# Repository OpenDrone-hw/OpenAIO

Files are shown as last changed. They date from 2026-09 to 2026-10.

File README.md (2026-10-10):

# OpenAIO

An all-in-one for toothpick-class FPV on 2 to 6 cells: flight controller,
4-in-1 ESC and ExpressLRS receiver on 25.5 x 25.5 mm mounting. It merges
three boards OpenDrone already makes: the ESC power stages, power, receiver
and all pads on this board, and the flight controller as the shared
OpenFC-Core module, a 15 x 15 mm LGA reflowed flat onto it, no connector.




The KiCad implementation lives in `hardware/`. Use Git for branch state and
manufacturing or test evidence for maturity claims.

## Why

The three-board stack works and OpenDrone already ships all three parts, but on
a toothpick the stack is most of the weight and all of the height. Merging them
removes two connectors, two sets of mounting hardware and a lot of wiring, and
those connectors are where builds fail.

The parts are proven separately, so this is an integration problem rather than
a research one. The only 6S AIO with onboard serial ELRS on the market is
closed and digital-only; an open one with analog OSD and blackbox has a place,
see the market research linked below.

## Specifications

From the design files. Not manufactured yet.

| | |
|---|---|
| Mounting | 25.5 x 25.5 mm, board 35.4 x 35.4 mm |
| Stack | 6 layers 1.6 mm, 2 oz outer; OpenFC-Core module on top as a 52-pad LGA |
| Input | 2-6S LiPo (6.0-25.2 V) |
| Flight controller | OpenFC-Core module: RP2350-class MCU, IMU, barometer, analog OSD, microSD blackbox; USB-C on this board |
| ESC | 4x AM32, AT32F421 + NSG2065Q per channel like the OpenESC boards |
| Receiver | ExpressLRS 2.4 GHz, ESP32-C3 + SX1281 |
| Assembly | Chosen per release; see production/. LCSC basic parts preferred |

## Constraints

- 25.5 x 25.5 mm mounting, the toothpick standard.
- Runs stock firmware: Betaflight on the FC, AM32 per ESC channel, ExpressLRS
  on the receiver. No forks.
- Reuses the manufactured circuits of OpenFC-Lite-Mini, OpenESC-20x20 and
  OpenRX where they fit; parts come from the shared library first.
- Assembly from LCSC parts, extended parts kept to a minimum; assembly house
  chosen per release, see production/.
- Do not start from the three schematics stitched together. That was tried,
  and it produced a board that looked finished and was not (recoverable at the
  `pre-reset-2026-08-13` tag). Start from the requirements.

## Prior art

The three designs this merges, all manufactured and flying:

- [OpenFC-Lite-Mini](https://github.com/OpenDrone-hw/OpenFC-Lite-Mini): the RP2354A flight controller
- [OpenESC-20x20](https://github.com/OpenDrone-hw/OpenESC-20x20): the AM32 4-in-1 power stage
- [OpenRX Lite](https://github.com/OpenDrone-hw/OpenRX-Lite): the ELRS receiver

Research so far, reference rather than decisions:

- [Market research](https://app.notion.com/p/3f5fe06764e1818e9158c512edd58138): competing toothpick and whoop AIOs, June 2026
- [Part alternatives](https://app.notion.com/p/3f5fe06764e1819eade0dc5bfbfdff7c): ESC-stage part alternatives, gate driver and FET options, March 2026
- The stitched design reset in August 2026 is in the git history before #9; reference for the thinking, not a design to continue from.

## Design questions

Resolve these only as part of user-requested design work:

- **Thermal.** Four power stages next to an MCU and a radio on 25.5 mm square,
  with no airflow guarantee. What is the continuous current budget on 2 oz
  outer copper?
- **RF isolation.** A 2.4 GHz receiver next to four switching power stages.
  Antenna placement, ground plane, shield can or not.

## In the line

What pairs with what, and what is available:
[opendrone.be](https://opendrone.be).

## Contributing

KiCad files cannot be merged, so say what you intend to change before you do,
on [Discord](https://discord.gg/v3sWmTcx3R). How everything works:
[CONTRIBUTING.md](CONTRIBUTING.md).

## License

Hardware licensed under [CERN-OHL-S-2.0](https://ohwr.org/cern_ohl_s_v2.txt),
see [LICENSE](LICENSE).

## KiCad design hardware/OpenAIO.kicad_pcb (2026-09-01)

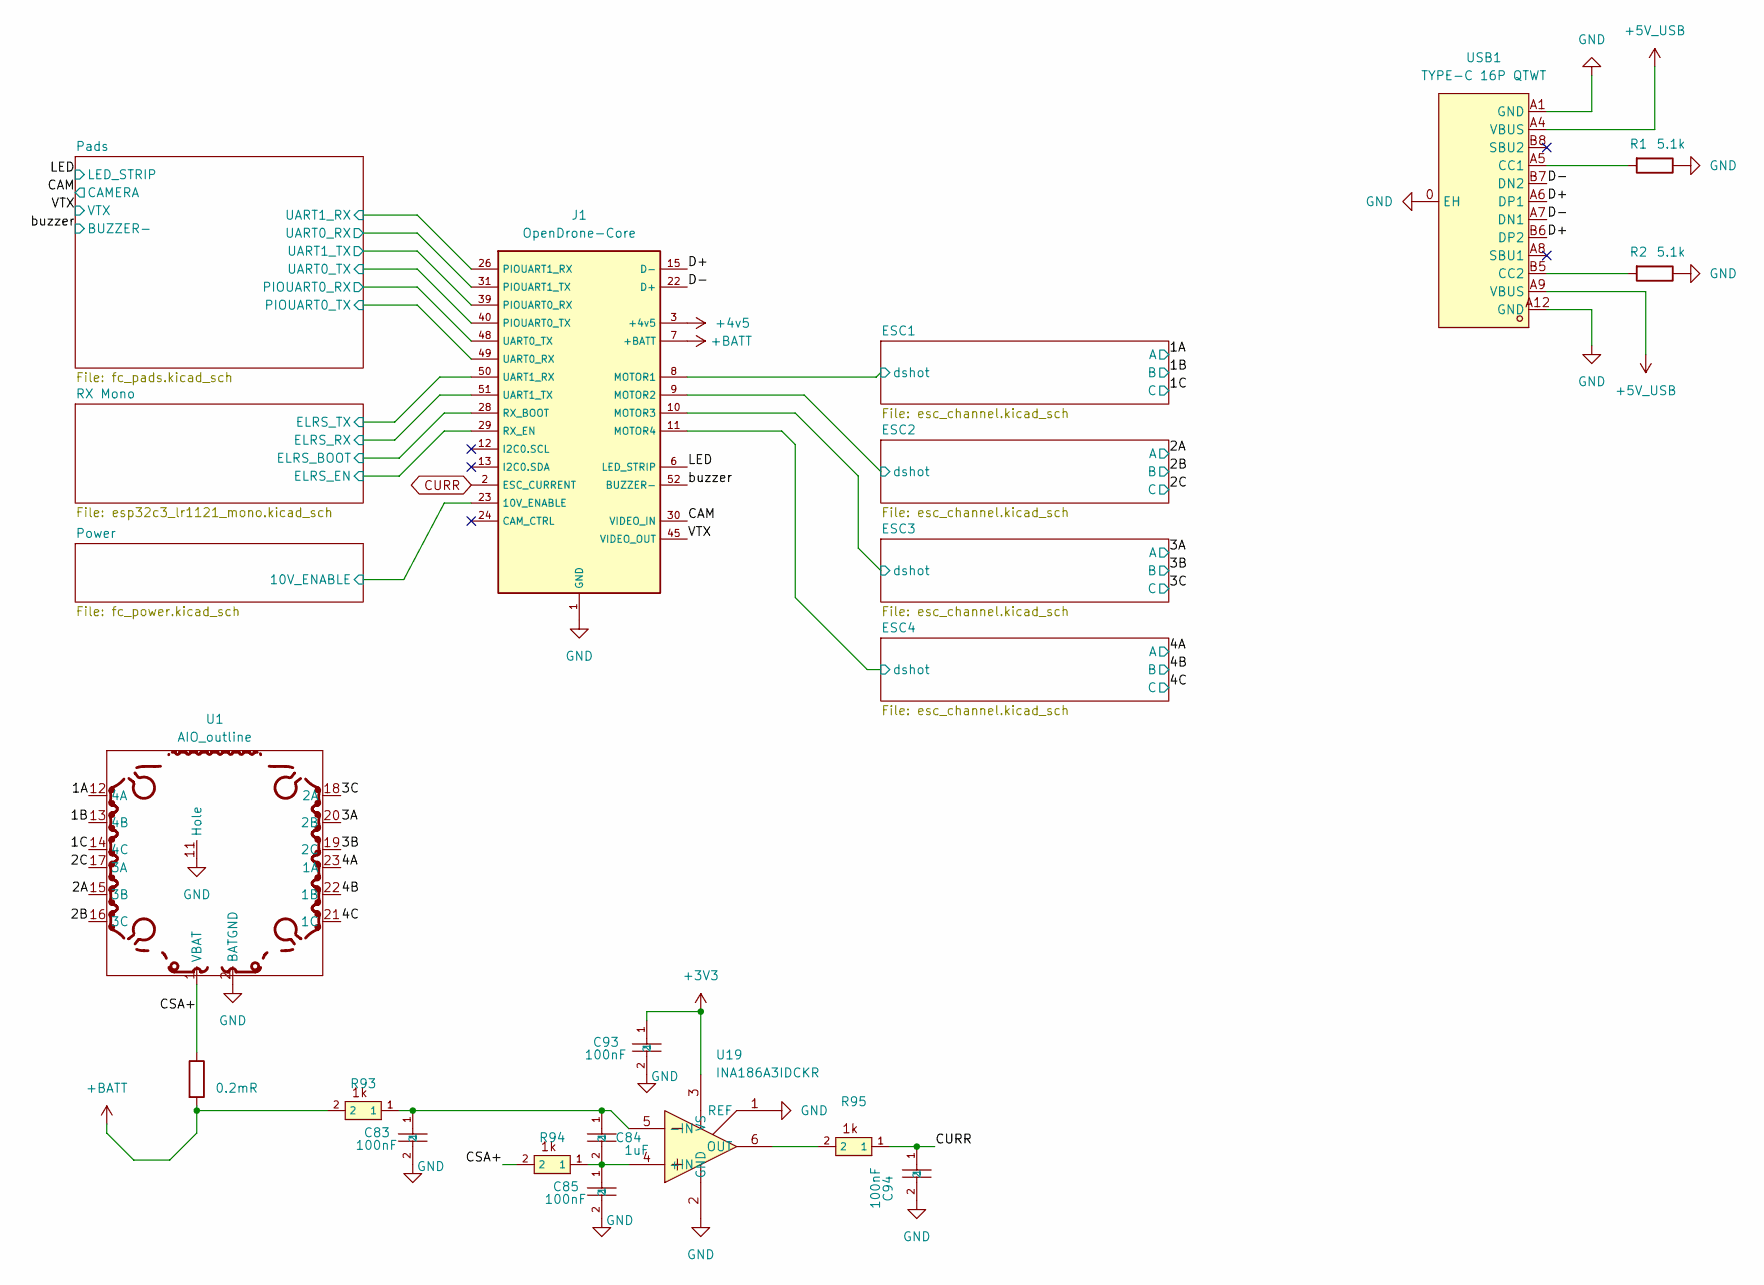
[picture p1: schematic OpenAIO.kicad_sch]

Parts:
C83, C85: 100nF; C_0402_WIDE; MPN CL05B104KB54PNC; LCSC C307331
C84: 1uF; C_0402_1005Metric; MPN CC0402KRX7R6BB105; LCSC C7500381
C93, C94: 100nF; C_0201_0603Metric; MPN GRM033R6YA104KE14D; LCSC C181043
J1: OpenDrone-Core; OpenDrone-Core_LGA_land
R1, R2: 5.1k; R_0201_0603Metric; MPN 0201WMF5101TEE; LCSC C270344
R93, R94: 1k; C_0201_0603Metric; MPN 0201WMF1001TEE; LCSC C270365
R95: 1k; R_0201_0603Metric; MPN 0201WMF1001TEE; LCSC C270365
Rsense2: 0.2mR; R_2512_6332Metric; MPN ASR-S-3-0.2F; LCSC C695806
U1: AIO_outline
U19: INA186A3IDCKR; SOT-363_SC-70-6; MPN INA186A3IDCKR; LCSC C2058245
USB1: TYPE-C 16P QTWT; USB-TYPE-C-SMD_TYPE-C-16P-QTWT; MPN TYPE-C 16P QTWT; LCSC C5187472

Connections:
+3V3: C93.1, U19.3 (VS); also elsewhere on the board
+4v5: J1.3 (+4v5); also elsewhere on the board
+5V_USB: USB1.A4 (VBUS), USB1.A9 (VBUS); also elsewhere on the board
+BATT: J1.7 (+BATT), R93.2, Rsense2.2; also elsewhere on the board
/1A: U1.12 (4A); also elsewhere on the board
/1B: U1.13 (4B); also elsewhere on the board
/1C: U1.14 (4C); also elsewhere on the board
/2A: U1.15 (3B); also elsewhere on the board
/2B: U1.16 (3C); also elsewhere on the board
/2C: U1.17 (3A); also elsewhere on the board
/3A: U1.20 (2B); also elsewhere on the board
/3B: U1.19 (2C); also elsewhere on the board
/3C: U1.18 (2A); also elsewhere on the board
/4A: U1.23 (1A); also elsewhere on the board
/4B: U1.22 (1B); also elsewhere on the board
/4C: U1.21 (1C); also elsewhere on the board
/CAM: J1.30 (VIDEO_IN); also elsewhere on the board
/CSA+: R94.2, Rsense2.1, U1.1 (VBAT)
/D+: J1.15 (D-), USB1.A6 (DP1), USB1.B6 (DP2)
/D-: J1.22 (D+), USB1.A7 (DN1), USB1.B7 (DN2)
/ESC1/dshot: J1.8 (MOTOR1); also elsewhere on the board
/ESC2/dshot: J1.9 (MOTOR2); also elsewhere on the board
/ESC3/dshot: J1.10 (MOTOR3); also elsewhere on the board
/ESC4/dshot: J1.11 (MOTOR4); also elsewhere on the board
/LED: J1.6 (LED_STRIP); also elsewhere on the board
/Pads/PIOUART0_TX: J1.49 (UART0_RX); also elsewhere on the board
/Pads/PU0RX: J1.48 (UART0_TX); also elsewhere on the board
/Pads/U1RX: J1.26 (PIOUART1_RX); also elsewhere on the board
/Pads/UART0_RX: J1.31 (PIOUART1_TX); also elsewhere on the board
/Pads/UART0_TX: J1.40 (PIOUART0_TX); also elsewhere on the board
/Pads/UART1_TX: J1.39 (PIOUART0_RX); also elsewhere on the board
/Power/10V_ENABLE: J1.23 (10V_ENABLE); also elsewhere on the board
/RX Mono/CHIP_EN: J1.29 (RX_EN); also elsewhere on the board
/RX Mono/ELRS_RX: J1.51 (UART1_TX); also elsewhere on the board
/RX Mono/ELRS_TX: J1.50 (UART1_RX); also elsewhere on the board
/VTX: J1.45 (VIDEO_OUT); also elsewhere on the board
/buzzer: J1.52 (BUZZER-); also elsewhere on the board
CURR: C94.1, R95.1
GND: C83.2, C85.2, C93.2, C94.2, J1.1 (GND), J1.4 (GND), J1.5 (GND), J1.14 (GND), J1.16 (GND), J1.17 (GND), J1.18 (GND), J1.19 (GND), J1.20 (GND), J1.21 (GND), J1.25 (GND), J1.27 (GND), J1.32 (GND), J1.33 (GND), J1.34 (GND), J1.35 (GND), J1.36 (GND), J1.37 (GND), J1.38 (GND), J1.41 (GND), J1.42 (GND), J1.43 (GND), J1.44 (GND), J1.46 (GND), J1.47 (GND), R1.1, R2.1, U1.2 (BATGND), U1.11 (Hole), U19.1 (REF), U19.2 (GND), USB1.0 (EH), USB1.A1 (GND), USB1.A12 (GND); also elsewhere on the board
unnamed: C84.2, C85.1, R94.1, U19.4 (+IN)
unnamed: C83.1, C84.1, R93.1, U19.5 (-IN)
unnamed: R95.2, U19.6 (OUT)
unnamed: R1.2, USB1.A5 (CC1)
unnamed: R2.2, USB1.B5 (CC2)

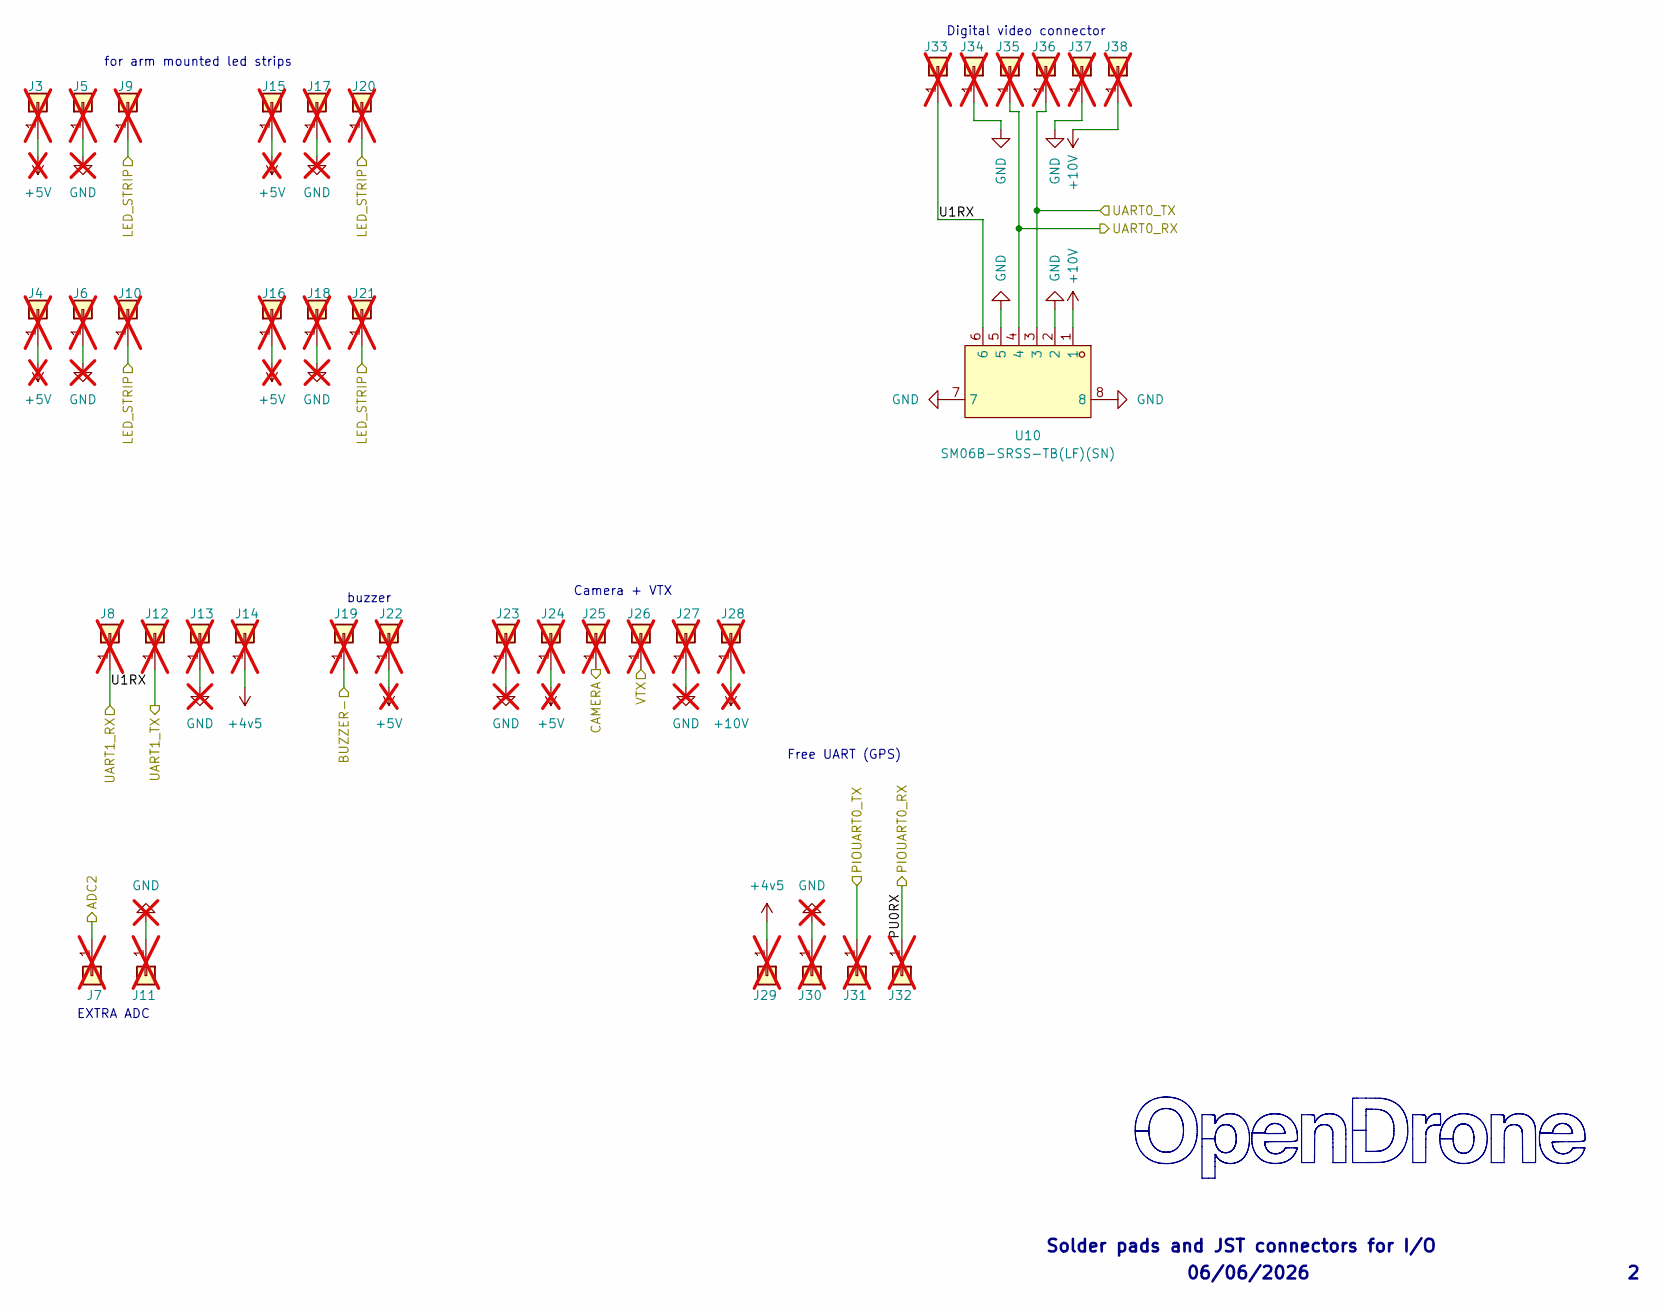
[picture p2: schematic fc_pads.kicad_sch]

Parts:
J3, J4, J5, J6, J7, J8, J9, J10, J11, J12, J13, J14, J15, J16, J17, J18, J19, J20, J21, J22, J23, J24, J25, J26, J27, J28, J29, J30, J31, J32, J33, J34, J35, J36, J37, J38: 5V; small_pad; not fitted
U10: SM06B-SRSS-TB(LF)(SN); CONN-SMD_SM06B-SRSS-TB-LF-SN; MPN SM06B-SRSS-TB(LF)(SN); LCSC C160405

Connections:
+4v5: J14.1 (Pin_1_1), J29.1 (Pin_1_1); also elsewhere on the board
+5V: J3.1 (Pin_1_1), J4.1 (Pin_1_1), J15.1 (Pin_1_1), J16.1 (Pin_1_1), J22.1 (Pin_1_1), J24.1 (Pin_1_1); also elsewhere on the board
+10V: J28.1 (Pin_1_1), J38.1 (Pin_1_1), U10.1; also elsewhere on the board
/CAM: J25.1 (Pin_1_1); also elsewhere on the board
/LED: J9.1 (Pin_1_1), J10.1 (Pin_1_1), J20.1 (Pin_1_1), J21.1 (Pin_1_1); also elsewhere on the board
/Pads/PIOUART0_TX: J31.1 (Pin_1_1); also elsewhere on the board
/Pads/PU0RX: J32.1 (Pin_1_1); also elsewhere on the board
/Pads/U1RX: J8.1 (Pin_1_1), J33.1, U10.6; also elsewhere on the board
/Pads/UART0_RX: J35.1 (Pin_1_1), U10.4; also elsewhere on the board
/Pads/UART0_TX: J36.1 (Pin_1_1), U10.3; also elsewhere on the board
/Pads/UART1_TX: J12.1 (Pin_1_1); also elsewhere on the board
/VTX: J26.1 (Pin_1_1); also elsewhere on the board
/buzzer: J19.1 (Pin_1_1); also elsewhere on the board
GND: J5.1 (Pin_1_1), J6.1 (Pin_1_1), J11.1, J13.1 (Pin_1_1), J17.1 (Pin_1_1), J18.1 (Pin_1_1), J23.1 (Pin_1_1), J27.1 (Pin_1_1), J30.1 (Pin_1_1), J34.1, J37.1 (Pin_1_1), U10.2, U10.5, U10.7, U10.8; also elsewhere on the board

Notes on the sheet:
Free UART (GPS)
Solder pads and JST connectors for I/O
06/06/2026
buzzer
Camera + VTX
Digital video connector
EXTRA ADC
for arm mounted led strips

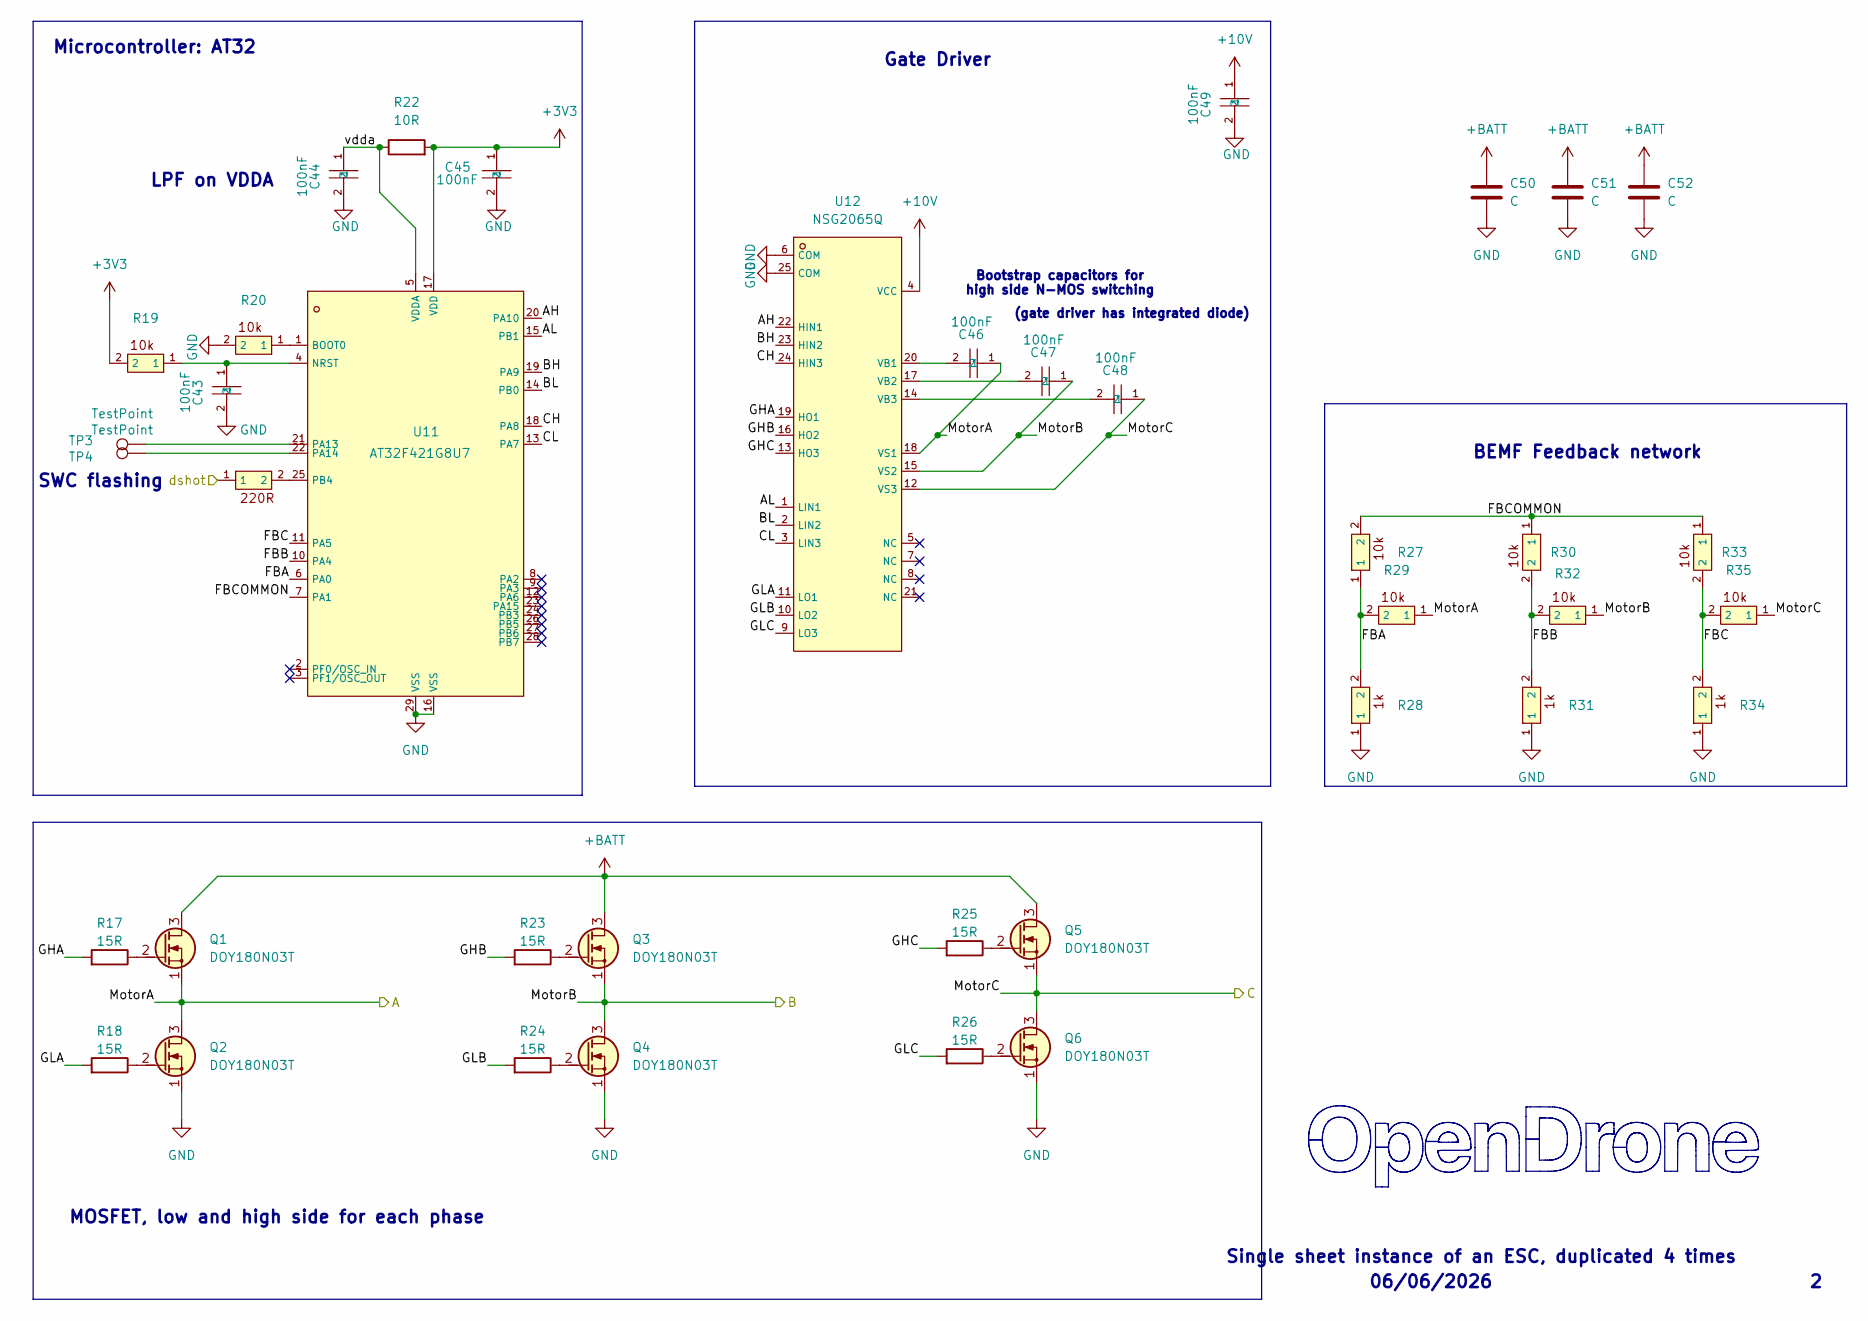
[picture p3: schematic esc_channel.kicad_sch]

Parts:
C43, C44, C45, C49: 100nF; C_0201_0603Metric; MPN GRM033R6YA104KE14D; LCSC C181043
C46, C47, C48: 100nF; C_0402_WIDE; MPN CL05B104KB54PNC; LCSC C307331
C50, C51, C52: C; C_0805_2012Metric
Q1, Q2, Q3, Q4, Q5, Q6: DOY180N03T; Diodes_PowerDI3333-8; MPN DOY180N03T; LCSC C49441966
R17, R18, R23, R24, R25, R26: 15R; R_0201_0603Metric; MPN 0201WMF150JTEE; LCSC C473542
R19, R20, R27, R29, R30, R32, R33, R35: 10k; R_0201_0603Metric; MPN RC0201FR-0710KL; LCSC C106225
R21: 220R; R_0201_0603Metric; MPN AC0201FR-07220RL; LCSC C226468
R22: 10R; R_0201_0603Metric; MPN RC0201FR-0710RL; LCSC C106226
R28, R31, R34: 1k; R_0201_0603Metric; MPN 0201WMF1001TEE; LCSC C270365
TP3, TP4: TestPoint; TestPoint_Pad_D1.0mm
U11: AT32F421G8U7; QFN-28_L4.0-W4.0-P0.40-TL-EP2.4; MPN AT32F421G8U7; LCSC C2765098
U12: NSG2065Q; QFN-24_L4.0-W4.0-P0.50-TL-EP2.8; MPN NSG2065Q; LCSC C41414478

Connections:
+3V3: C45.1, R19.2, R22.2, U11.17 (VDD); also elsewhere on the board
+10V: C49.1, U12.4 (VCC); also elsewhere on the board
+BATT: C50.1, C51.1, C52.1, Q1.3 (D), Q3.3 (D), Q5.3 (D); also elsewhere on the board
/1A: C46.1, Q1.1 (S), Q2.3 (D), R29.1, U12.18 (VS1); also elsewhere on the board
/1B: C47.1, Q3.1 (S), Q4.3 (D), R32.1, U12.15 (VS2); also elsewhere on the board
/1C: C48.1, Q5.1 (S), Q6.3 (D), R35.1, U12.12 (VS3); also elsewhere on the board
/ESC1/AH: U11.20 (PA10), U12.22 (HIN1)
/ESC1/AL: U11.15 (PB1), U12.1 (LIN1)
/ESC1/BH: U11.19 (PA9), U12.23 (HIN2)
/ESC1/BL: U11.14 (PB0), U12.2 (LIN2)
/ESC1/CH: U11.18 (PA8), U12.24 (HIN3)
/ESC1/CL: U11.13 (PA7), U12.3 (LIN3)
/ESC1/FBA: R27.1, R28.2, R29.2, U11.6 (PA0)
/ESC1/FBB: R30.2, R31.2, R32.2, U11.10 (PA4)
/ESC1/FBC: R33.2, R34.2, R35.2, U11.11 (PA5)
/ESC1/FBCOMMON: R27.2, R30.1, R33.1, U11.7 (PA1)
/ESC1/GHA: R17.1, U12.19 (HO1)
/ESC1/GHB: R23.1, U12.16 (HO2)
/ESC1/GHC: R25.1, U12.13 (HO3)
/ESC1/GLA: R18.1, U12.11 (LO1)
/ESC1/GLB: R24.1, U12.10 (LO2)
/ESC1/GLC: R26.1, U12.9 (LO3)
/ESC1/dshot: R21.1; also elsewhere on the board
/ESC1/vdda: C44.1, R22.1, U11.5 (VDDA)
GND: C43.2, C44.2, C45.2, C49.2, C50.2, C51.2, C52.2, Q2.1 (S), Q4.1 (S), Q6.1 (S), R20.2, R28.1, R31.1, R34.1, U11.16 (VSS), U11.29 (VSS), U12.6 (COM), U12.25 (COM); also elsewhere on the board
unnamed: Q1.2 (G), R17.2
unnamed: Q2.2 (G), R18.2
unnamed: Q3.2 (G), R23.2
unnamed: Q4.2 (G), R24.2
unnamed: Q5.2 (G), R25.2
unnamed: Q6.2 (G), R26.2
unnamed: R20.1, U11.1 (BOOT0)
unnamed: C43.1, R19.1, U11.4 (NRST)
unnamed: TP3.1 (1_1), U11.21 (PA13)
unnamed: TP4.1 (1_1), U11.22 (PA14)
unnamed: R21.2, U11.25 (PB4)
unnamed: C46.2, U12.20 (VB1)
unnamed: C47.2, U12.17 (VB2)
unnamed: C48.2, U12.14 (VB3)

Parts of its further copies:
C53, C56, C58, C66, C67, C68, C73, C76, C78: 100nF; C_0402_WIDE; MPN CL05B104KB54PNC; LCSC C307331
C54, C55, C57, C59, C63, C64, C65, C69, C74, C75, C77, C79: 100nF; C_0201_0603Metric; MPN GRM033R6YA104KE14D; LCSC C181043
C60, C61, C62, C70, C71, C72, C80, C81, C82: C; C_0805_2012Metric
Q7, Q8, Q9, Q10, Q11, Q12, Q13, Q14, Q15, Q16, Q17, Q18, Q19, Q20, Q21, Q22, Q23, Q24: DOY180N03T; Diodes_PowerDI3333-8; MPN DOY180N03T; LCSC C49441966
R37, R42, R43, R44, R45, R55, R56, R61, R62, R63, R64, R80, R81, R82, R83: 15R; R_0201_0603Metric; MPN 0201WMF150JTEE; LCSC C473542
R38, R39, R46, R48, R49, R51, R52, R54, R57, R58, R67, R68, R70, R73, R76, R84, R86, R87, R89, R90, R92: 10k; R_0201_0603Metric; MPN RC0201FR-0710KL; LCSC C106225
R40, R59, R78: 220R; R_0201_0603Metric; MPN AC0201FR-07220RL; LCSC C226468
R47, R50, R53, R66, R69, R72, R85, R88, R91: 1k; R_0201_0603Metric; MPN 0201WMF1001TEE; LCSC C270365
R60, R79: 10R; R_0201_0603Metric; MPN RC0201FR-0710RL; LCSC C106226
TP5, TP6, TP7, TP8, TP9, TP10: TestPoint; TestPoint_Pad_D1.0mm
U13, U15, U17: AT32F421G8U7; QFN-28_L4.0-W4.0-P0.40-TL-EP2.4; MPN AT32F421G8U7; LCSC C2765098
U14, U16, U18: NSG2065Q; QFN-24_L4.0-W4.0-P0.50-TL-EP2.8; MPN NSG2065Q; LCSC C41414478

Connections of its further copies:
+3V3: C55.1, C65.1, C75.1, R38.2, R57.2, R60.2, R76.2, R79.2, U13.17 (VDD), U15.17 (VDD), U17.17 (VDD); also elsewhere on the board
+10V: C59.1, C69.1, C79.1, U14.4 (VCC), U16.4 (VCC), U18.4 (VCC); also elsewhere on the board
+BATT: C60.1, C61.1, C62.1, C70.1, C71.1, C72.1, C80.1, C81.1, C82.1, Q7.3 (D), Q9.3 (D), Q11.3 (D), Q13.3 (D), Q15.3 (D), Q17.3 (D), Q19.3 (D), Q21.3 (D), Q23.3 (D); also elsewhere on the board
/2A: C56.1, Q7.1 (S), Q8.3 (D), R48.1, U14.18 (VS1); also elsewhere on the board
/2B: C57.1, Q9.1 (S), Q10.3 (D), R51.1, U14.15 (VS2); also elsewhere on the board
/2C: C58.1, Q11.1 (S), Q12.3 (D), R54.1, U14.12 (VS3); also elsewhere on the board
/3A: C66.1, Q13.1 (S), Q14.3 (D), R67.1, U16.18 (VS1); also elsewhere on the board
/3B: C67.1, Q15.1 (S), Q16.3 (D), R70.1, U16.15 (VS2); also elsewhere on the board
/3C: C68.1, Q17.1 (S), Q18.3 (D), R73.1, U16.12 (VS3); also elsewhere on the board
/4A: C76.1, Q19.1 (S), Q20.3 (D), R86.1, U18.18 (VS1); also elsewhere on the board
/4B: C77.1, Q21.1 (S), Q22.3 (D), R89.1, U18.15 (VS2); also elsewhere on the board
/4C: C78.1, Q23.1 (S), Q24.3 (D), R92.1, U18.12 (VS3); also elsewhere on the board
/ESC2/AH: U13.20 (PA10), U14.22 (HIN1)
/ESC2/AL: U13.15 (PB1), U14.1 (LIN1)
/ESC2/BH: U13.19 (PA9), U14.23 (HIN2)
/ESC2/BL: U13.14 (PB0), U14.2 (LIN2)
/ESC2/CH: U13.18 (PA8), U14.24 (HIN3)
/ESC2/CL: U13.13 (PA7), U14.3 (LIN3)
/ESC2/FBA: R46.1, R47.2, R48.2, U13.6 (PA0)
/ESC2/FBB: R49.2, R50.2, R51.2, U13.10 (PA4)
/ESC2/FBC: R52.2, R53.2, R54.2, U13.11 (PA5)
/ESC2/FBCOMMON: R46.2, R49.1, R52.1, U13.7 (PA1)
/ESC2/GHA: U14.19 (HO1); also elsewhere on the board
/ESC2/GHB: R42.1, U14.16 (HO2)
/ESC2/GHC: R44.1, U14.13 (HO3)
/ESC2/GLA: R37.1, U14.11 (LO1)
/ESC2/GLB: R43.1, U14.10 (LO2)
/ESC2/GLC: R45.1, U14.9 (LO3)
/ESC2/dshot: R40.1; also elsewhere on the board
/ESC2/vdda: C54.1, U13.5 (VDDA); also elsewhere on the board
/ESC3/AH: U15.20 (PA10), U16.22 (HIN1)
/ESC3/AL: U15.15 (PB1), U16.1 (LIN1)
/ESC3/BH: U15.19 (PA9), U16.23 (HIN2)
/ESC3/BL: U15.14 (PB0), U16.2 (LIN2)
/ESC3/CH: U15.18 (PA8), U16.24 (HIN3)
/ESC3/CL: U15.13 (PA7), U16.3 (LIN3)
/ESC3/FBA: R66.2, R67.2, U15.6 (PA0); also elsewhere on the board
/ESC3/FBB: R68.2, R69.2, R70.2, U15.10 (PA4)
/ESC3/FBC: R72.2, R73.2, U15.11 (PA5); also elsewhere on the board
/ESC3/FBCOMMON: R68.1, U15.7 (PA1); also elsewhere on the board
/ESC3/GHA: R55.1, U16.19 (HO1)
/ESC3/GHB: R61.1, U16.16 (HO2)
/ESC3/GHC: R63.1, U16.13 (HO3)
/ESC3/GLA: R56.1, U16.11 (LO1)
/ESC3/GLB: R62.1, U16.10 (LO2)
/ESC3/GLC: R64.1, U16.9 (LO3)
/ESC3/dshot: R59.1; also elsewhere on the board
/ESC3/vdda: C64.1, R60.1, U15.5 (VDDA)
/ESC4/AH: U17.20 (PA10), U18.22 (HIN1)
/ESC4/AL: U17.15 (PB1), U18.1 (LIN1)
/ESC4/BH: U17.19 (PA9), U18.23 (HIN2)
/ESC4/BL: U17.14 (PB0), U18.2 (LIN2)
/ESC4/CH: U17.18 (PA8), U18.24 (HIN3)
/ESC4/CL: U17.13 (PA7), U18.3 (LIN3)
/ESC4/FBA: R84.1, R85.2, R86.2, U17.6 (PA0)
/ESC4/FBB: R87.2, R88.2, R89.2, U17.10 (PA4)
/ESC4/FBC: R90.2, R91.2, R92.2, U17.11 (PA5)
/ESC4/FBCOMMON: R84.2, R87.1, R90.1, U17.7 (PA1)
/ESC4/GHA: U18.19 (HO1); also elsewhere on the board
/ESC4/GHB: R80.1, U18.16 (HO2)
/ESC4/GHC: R82.1, U18.13 (HO3)
/ESC4/GLA: U18.11 (LO1); also elsewhere on the board
/ESC4/GLB: R81.1, U18.10 (LO2)
/ESC4/GLC: R83.1, U18.9 (LO3)
/ESC4/dshot: R78.1; also elsewhere on the board
/ESC4/vdda: C74.1, R79.1, U17.5 (VDDA)
GND: C53.2, C54.2, C55.2, C59.2, C60.2, C61.2, C62.2, C63.2, C64.2, C65.2, C69.2, C70.2, C71.2, C72.2, C73.2, C74.2, C75.2, C79.2, C80.2, C81.2, C82.2, Q8.1 (S), Q10.1 (S), Q12.1 (S), Q14.1 (S), Q16.1 (S), Q18.1 (S), Q20.1 (S), Q22.1 (S), Q24.1 (S), R39.2, R47.1, R50.1, R53.1, R58.2, R66.1, R69.1, R72.1, R85.1, R88.1, R91.1, U13.16 (VSS), U13.29 (VSS), U14.6 (COM), U14.25 (COM), U15.16 (VSS), U15.29 (VSS), U16.6 (COM), U16.25 (COM), U17.16 (VSS), U17.29 (VSS), U18.6 (COM), U18.25 (COM); also elsewhere on the board
unnamed 141: Q7.2 (G); also elsewhere on the board
unnamed: Q8.2 (G), R37.2
unnamed: Q9.2 (G), R42.2
unnamed: Q10.2 (G), R43.2
unnamed: Q11.2 (G), R44.2
unnamed: Q12.2 (G), R45.2
unnamed: Q13.2 (G), R55.2
unnamed: Q14.2 (G), R56.2
unnamed: Q15.2 (G), R61.2
unnamed: Q16.2 (G), R62.2
unnamed: Q17.2 (G), R63.2
unnamed: Q18.2 (G), R64.2
unnamed 153: Q19.2 (G); also elsewhere on the board
unnamed 154: Q20.2 (G); also elsewhere on the board
unnamed: Q21.2 (G), R80.2
unnamed: Q22.2 (G), R81.2
unnamed: Q23.2 (G), R82.2
unnamed: Q24.2 (G), R83.2
unnamed: R39.1, U13.1 (BOOT0)
unnamed: C53.1, R38.1, U13.4 (NRST)
unnamed: TP5.1 (1_1), U13.21 (PA13)
unnamed: TP6.1 (1_1), U13.22 (PA14)
unnamed: R40.2, U13.25 (PB4)
unnamed: C56.2, U14.20 (VB1)
unnamed: C57.2, U14.17 (VB2)
unnamed: C58.2, U14.14 (VB3)
unnamed: R58.1, U15.1 (BOOT0)
unnamed: C63.1, R57.1, U15.4 (NRST)
unnamed: TP7.1 (1_1), U15.21 (PA13)
unnamed: TP8.1 (1_1), U15.22 (PA14)
unnamed: R59.2, U15.25 (PB4)
unnamed: C66.2, U16.20 (VB1)
unnamed: C67.2, U16.17 (VB2)
unnamed: C68.2, U16.14 (VB3)
unnamed 202: U17.1 (BOOT0); also elsewhere on the board
unnamed: C73.1, R76.1, U17.4 (NRST)
unnamed: TP9.1 (1_1), U17.21 (PA13)
unnamed: TP10.1 (1_1), U17.22 (PA14)
unnamed: R78.2, U17.25 (PB4)
unnamed: C76.2, U18.20 (VB1)
unnamed: C77.2, U18.17 (VB2)
unnamed: C78.2, U18.14 (VB3)

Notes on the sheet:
Bootstrap capacitors for high side N-MOS switching
Gate Driver
MOSFET, low and high side for each phase
Single sheet instance of an ESC, duplicated 4 times
Microcontroller: AT32
SWC flashing
(gate driver has integrated diode)
06/06/2026
BEMF Feedback network
LPF on VDDA

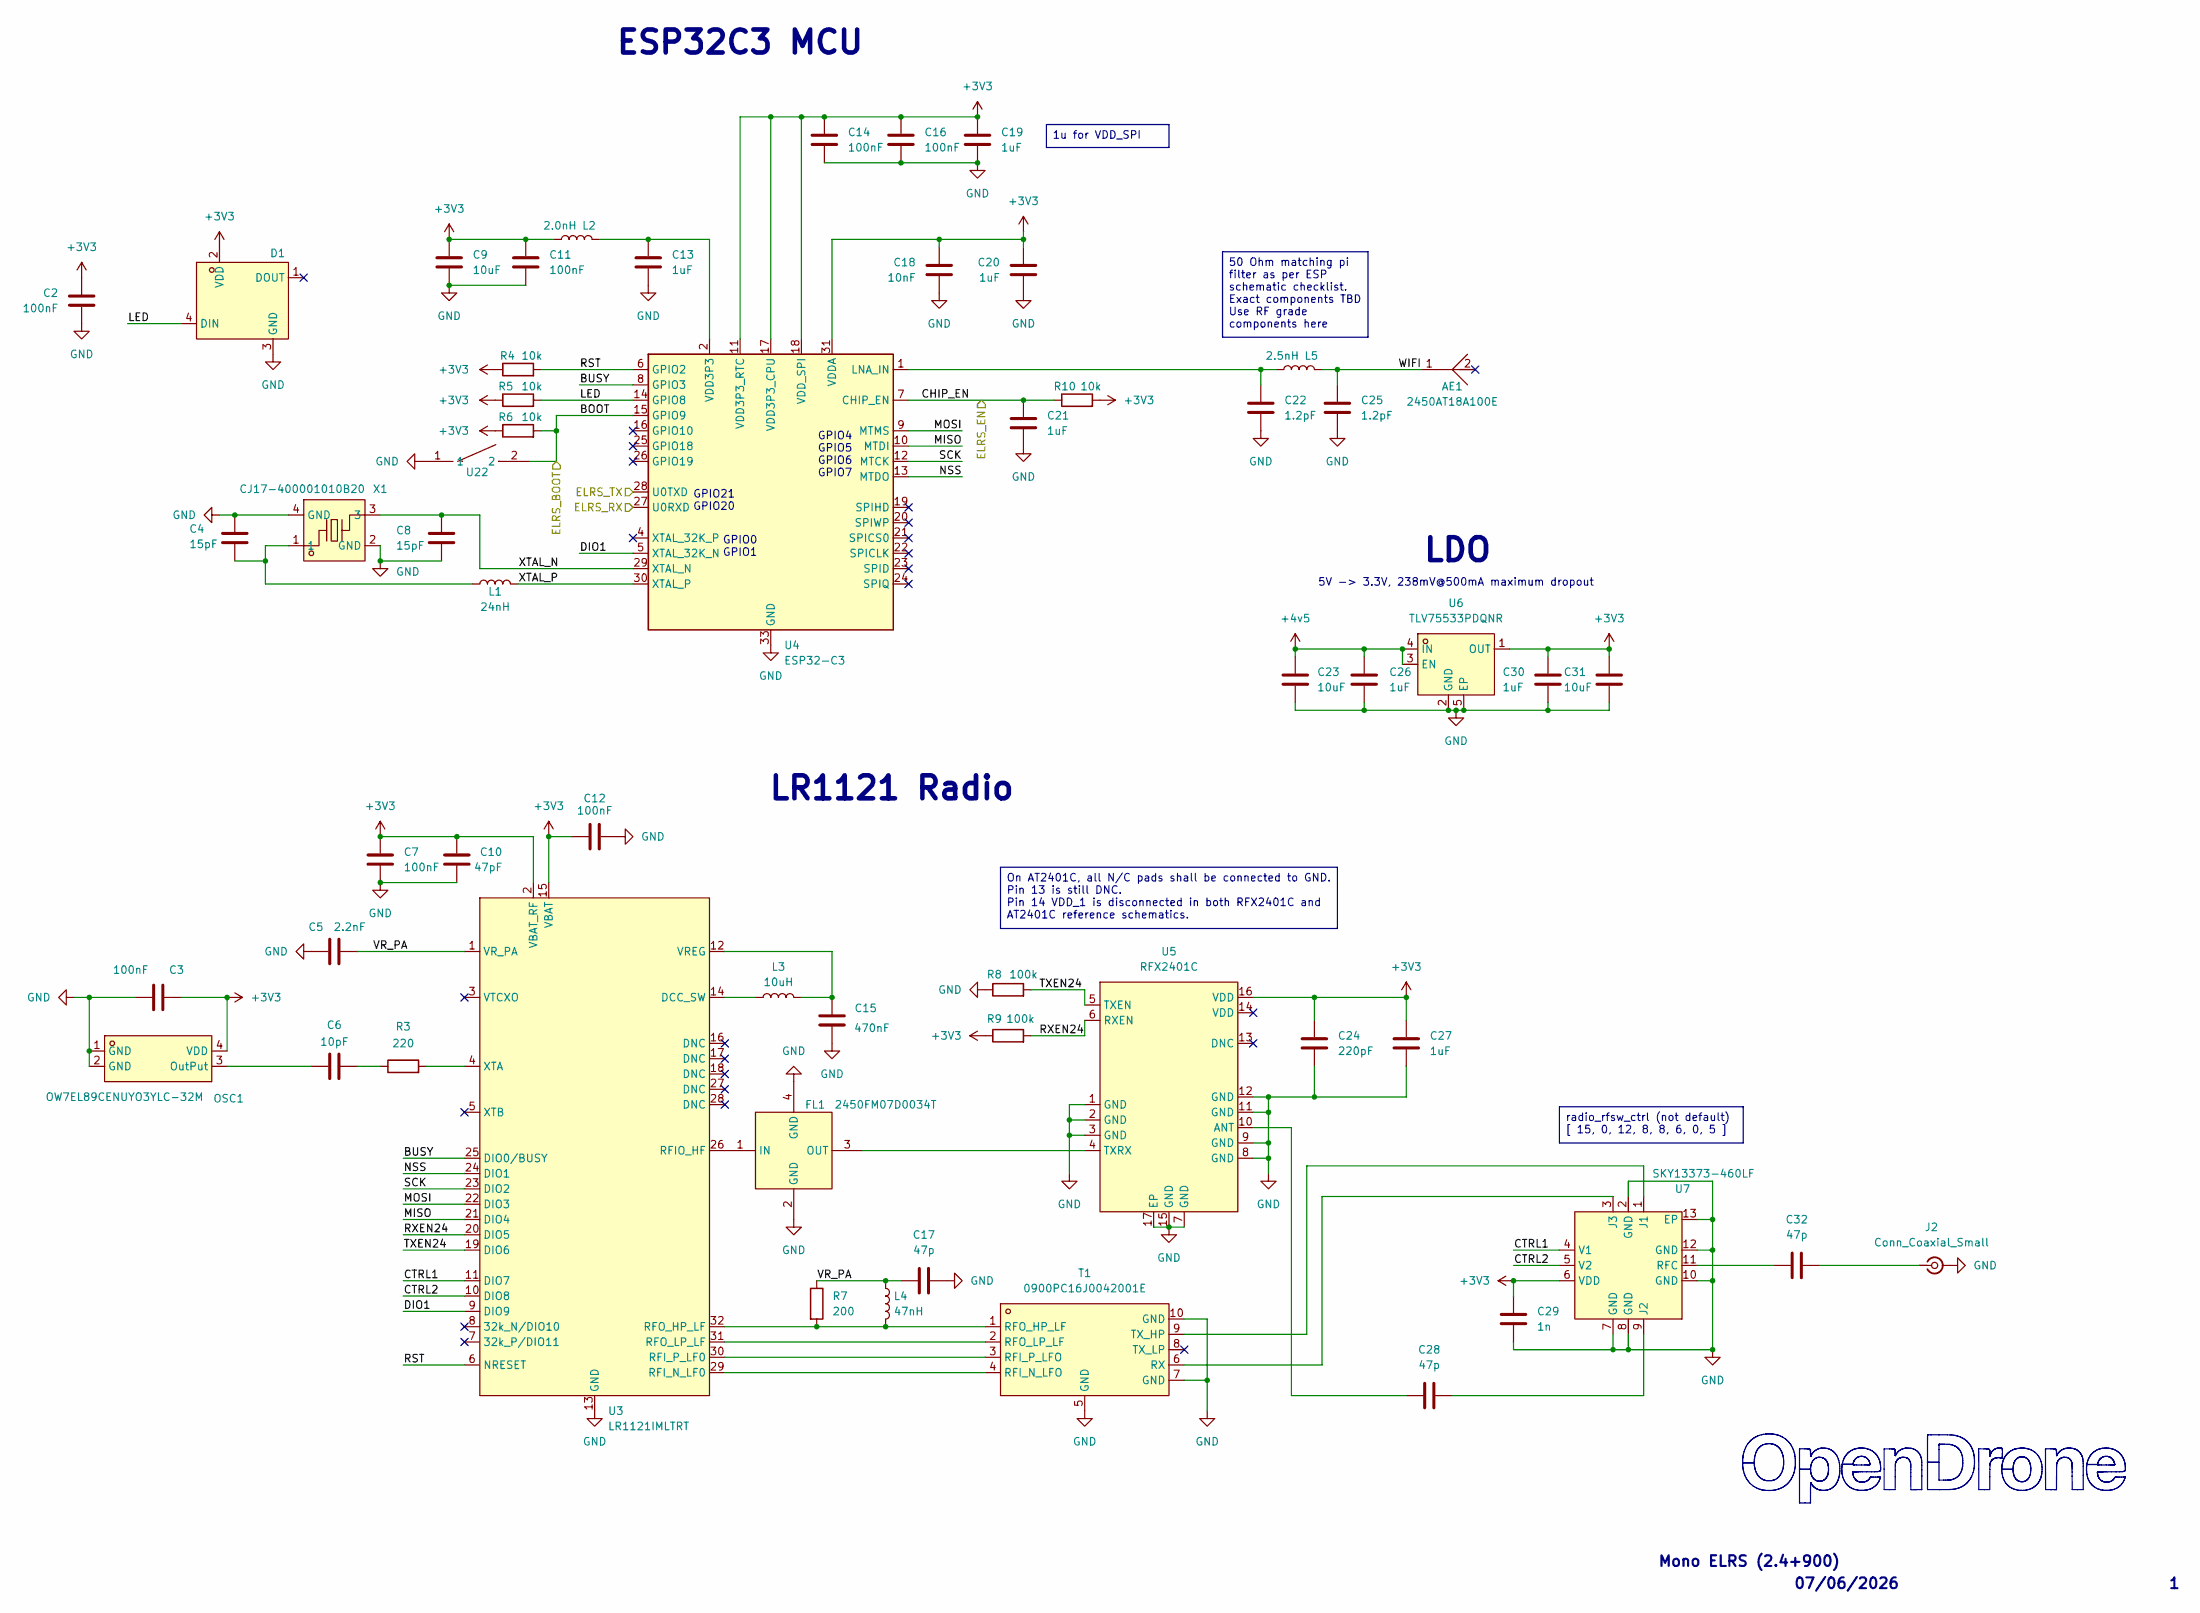
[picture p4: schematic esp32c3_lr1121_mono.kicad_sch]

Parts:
AE1: 2450AT18A100E; ANT-SMD_L3.2-W1.6; MPN 2450AT18A100E; LCSC Part C89334
C2, C3, C7, C11, C12, C14, C16: 100nF; C_0201_0603Metric; MPN GRM033R61E104KE14D; LCSC C76939
C4, C8: 15pF; C_0201_0603Metric; MPN GRM0335C1H150JA01D; LCSC C85891
C5: 2.2nF; C_0201_0603Metric; MPN GRM033R71E222KA12D; LCSC C161488
C6: 10pF; C_0201_0603Metric; MPN GRM0335C1H100FA01D; LCSC C384956
C9: 10uF; C_0402_1005Metric; MPN GRM155R60J106ME44D; LCSC C76991
C10: 47pF; C_0201_0603Metric; MPN GRM0335C1H470JA01D; LCSC C85908
C13, C19, C20, C21, C27: 1uF; C_0201_0603Metric; MPN GRM033R61A105ME44D; LCSC C76935
C15: 470nF; C_0201_0603Metric; MPN GRM033R60J474KE90D; LCSC C85926
C17, C28, C32: 47p; C_0201_0603Metric; MPN GRM0335C1H470JA01D; LCSC C85908
C18: 10nF; C_0201_0603Metric; MPN GRM033R61A103KA01J; LCSC C2168164
C22, C25: 1.2pF; C_0201_0603Metric; MPN GRM0335C1H1R2BA01D; LCSC C85895
C23, C31: 10uF; C_0402_1005Metric; LCSC C15525
C24: 220pF; C_0201_0603Metric; MPN GRM0335C1E221JA01D; LCSC C907939
C26, C30: 1uF; C_0201_0603Metric; LCSC C76935
C29: 1n; C_0201_0603Metric; MPN GRM033R71H102KA12D; LCSC C85934
D1: XL-1010RGBC-WS2812B; LED-SMD_4P-L1.0-W1.0-TL_XL-1010RGBC-WS2812B; MPN XL-1010RGBC-2812B; LCSC C5349953
FL1: 2450FM07D0034T; FILTER-SMD_4P-L1.0-W0.5-L; MPN 2450FM07D0034T; LCSC Part_1 C2651081
J2: Conn_Coaxial_Small; U.FL_Hirose_U.FL-R-SMT-1_Vertical; MPN U.FL-R-SMT-1(80); LCSC C88374
L1: 24nH; L_0201_0603Metric; MPN LQP03TN24NH02D; LCSC C206441
L2: 2.0nH; L_0201_0603Metric; MPN LQP03TN2N0B02D; LCSC C86125
L3: 10uH; L_0603_1608Metric; MPN MLZ1608N100LT000; LCSC C194437
L4: 47nH; L_0402_1005Metric; MPN LQW15AN47NJ00D; LCSC C192855
L5: 2.5nH; L_0201_0603Metric; MPN LQP03TN2N5C02D; LCSC C206435
OSC1: OW7EL89CENUYO3YLC-32M; OSC-SMD_4P-L2.0-W1.6-BL_TXC_7Z; MPN OW7EL89CENUYO3YLC-32M; LCSC C22381772
R3: 220; R_0201_0603Metric; MPN ERJ-1GNF2200C; LCSC C2074788
R4, R5, R6, R10: 10k; R_0201_0603Metric; MPN RC0201FR-0710KL; LCSC C106225
R7: 200; R_0201_0603Metric; MPN RC0201FR-07200RL; LCSC C274337
R8, R9: 100k; R_0201_0603Metric; MPN RC0201FR-07100KL; LCSC C106224
T1: 0900PC16J0042001E; FILTER-SMD_10P-L2.0-W1.6-BL; MPN 0900PC16J0042001E; LCSC C19842466
U3: LR1121IMLTRT; QFN-32-1EP_5x5mm_P0.5mm_EP3.7x3.7mm; MPN LR1121IMLTRT; LCSC C7498014
U4: ESP32-C3; QFN-32-1EP_5x5mm_P0.5mm_EP3.7x3.7mm
U5: RFX2401C; QFN-16_L3.0-W3.0-P0.50-BL-EP1.7; MPN RFX2401C; LCSC C19213
U6: TLV75533PDQNR; X2SON-4_L1.0-W1.0-P0.65-TL-EP; LCSC Part C2861882
U7: SKY13373-460LF; QFN-12_EP_2x2_Pitch0.5mm
U22: TS2306A 240GF MSM 9_C2976675; SW-SMD_4P-L3.0-W2.0-P0.85-LS3.5; MPN TS2306A 240gf MSM 9; LCSC C2976675
X1: CJ17-400001010B20; CRYSTAL-SMD_4P-L1.6-W1.2-BL; MPN CJ17-400001010B20; LCSC Part C2875272

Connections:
+3V3: C2.1, C3.2, C7.1, C9.1, C10.1, C11.1, C12.1, C14.1, C16.1, C18.1, C19.1, C20.1, C24.1, C27.1, C29.1, C30.1, C31.1, D1.2 (VDD), L2.2, OSC1.4 (VDD), R4.1, R5.1, R6.1, R9.1, R10.2, U3.2 (VBAT_RF), U3.15 (VBAT), U4.11 (VDD3P3_RTC), U4.17 (VDD3P3_CPU), U4.18 (VDD_SPI), U4.31 (VDDA), U4.32 (VDDA), U5.16 (VDD), U6.1 (OUT), U7.6 (VDD); also elsewhere on the board
+4v5: C23.1, C26.1, U6.3 (EN), U6.4 (IN); also elsewhere on the board
/RX Mono/BOOT: R6.2, U4.15 (GPIO9), U22.2
/RX Mono/BUSY: U3.25 (DIO0/BUSY), U4.8 (GPIO3)
/RX Mono/CHIP_EN: C21.1, R10.1, U4.7 (CHIP_EN); also elsewhere on the board
/RX Mono/CTRL1: U3.11 (DIO7), U7.4 (V1)
/RX Mono/CTRL2: U3.10 (DIO8), U7.5 (V2)
/RX Mono/DIO1: U3.9 (DIO9), U4.5 (XTAL_32K_N)
/RX Mono/ELRS_RX: U4.27 (U0RXD); also elsewhere on the board
/RX Mono/ELRS_TX: U4.28 (U0TXD); also elsewhere on the board
/RX Mono/LED: D1.4 (DIN), R5.2, U4.14 (GPIO8)
/RX Mono/MISO: U3.21 (DIO4), U4.10 (MTDI)
/RX Mono/MOSI: U3.22 (DIO3), U4.9 (MTMS)
/RX Mono/NSS: U3.24 (DIO1), U4.13 (MTDO)
/RX Mono/RST: R4.2, U3.6 (NRESET), U4.6 (GPIO2)
/RX Mono/RXEN24: R9.2, U3.20 (DIO5), U5.6 (RXEN)
/RX Mono/SCK: U3.23 (DIO2), U4.12 (MTCK)
/RX Mono/TXEN24: R8.2, U3.19 (DIO6), U5.5 (TXEN)
/RX Mono/VR_PA: C5.1, C17.1, L4.1, R7.1, U3.1 (VR_PA)
/RX Mono/WIFI: AE1.1, C25.1, L5.1
/RX Mono/XTAL_N: C8.1, U4.29 (XTAL_N), X1.3
/RX Mono/XTAL_P: L1.2, U4.30 (XTAL_P)
GND: C2.2, C3.1, C4.2, C5.2, C7.2, C8.2, C9.2, C10.2, C11.2, C12.2, C13.2, C14.2, C15.1, C16.2, C17.2, C18.2, C19.2, C20.2, C21.2, C22.2, C23.2, C24.2, C25.2, C26.2, C27.2, C29.2, C30.2, C31.2, D1.3 (GND), FL1.2 (GND), FL1.4 (GND), J2.2 (Ext), OSC1.1 (GND), OSC1.2 (GND), R8.1, T1.5 (GND), T1.7 (GND), T1.10 (GND), U3.13 (GND), U3.33 (EP), U4.33 (GND), U5.1 (GND), U5.2 (GND), U5.3 (GND), U5.7 (GND), U5.8 (GND), U5.9 (GND), U5.11 (GND), U5.12 (GND), U5.15 (GND), U5.17 (EP), U6.2 (GND), U6.5 (EP), U7.2 (GND), U7.7 (GND), U7.8 (GND), U7.10 (GND), U7.12 (GND), U7.13 (EP), U22.1, X1.2 (GND), X1.4 (GND); also elsewhere on the board
unnamed: C4.1, L1.1, X1.1
unnamed: C6.1, R3.1
unnamed: C13.1, L2.1, U4.2 (VDD3P3), U4.3 (VDD3P3)
unnamed: FL1.1 (IN), U3.26 (RFIO_HF)
unnamed: FL1.3 (OUT), U5.4 (TXRX)
unnamed: C32.2, J2.1 (In)
unnamed: C6.2, OSC1.3 (OutPut)
unnamed: T1.4 (RFI_N_LFO), U3.29 (RFI_N_LF0)
unnamed: T1.3 (RFI_P_LFO), U3.30 (RFI_P_LF0)
unnamed: L4.2, R7.2, T1.1 (RFO_HP_LF), U3.32 (RFO_HP_LF)
unnamed: T1.2 (RFO_LP_LF), U3.31 (RFO_LP_LF)
unnamed: T1.6 (RX), U7.3 (J3)
unnamed: T1.9 (TX_HP), U7.1 (J1)
unnamed: L3.1, U3.14 (DCC_SW)
unnamed: C15.2, L3.2, U3.12 (VREG)
unnamed: R3.2, U3.4 (XTA)
unnamed: C22.1, L5.2, U4.1 (LNA_IN)
unnamed: C28.1, U5.10 (ANT)
unnamed: C28.2, U7.9 (J2)
unnamed: C32.1, U7.11 (RFC)

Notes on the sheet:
GPIO0 GPIO1
LR1121 Radio
GPIO21 GPIO20
5V -> 3.3V, 238mV@500mA maximum dropout
07/06/2026
ESP32C3 MCU
Mono ELRS (2.4+900)
LDO
GPIO4 GPIO5 GPIO6 GPIO7
On AT2401C, all N/C pads shall be connected to GND. Pin 13 is still DNC. Pin 14 VDD_1 is disconnected in both RFX2401C and AT2401C reference schematics.
50 Ohm matching pi filter as per ESP schematic checklist. Exact components TBD Use RF grade components here
radio_rfsw_ctrl (not default) [ 15, 0, 12, 8, 8, 6, 0, 5 ]
1u for VDD_SPI

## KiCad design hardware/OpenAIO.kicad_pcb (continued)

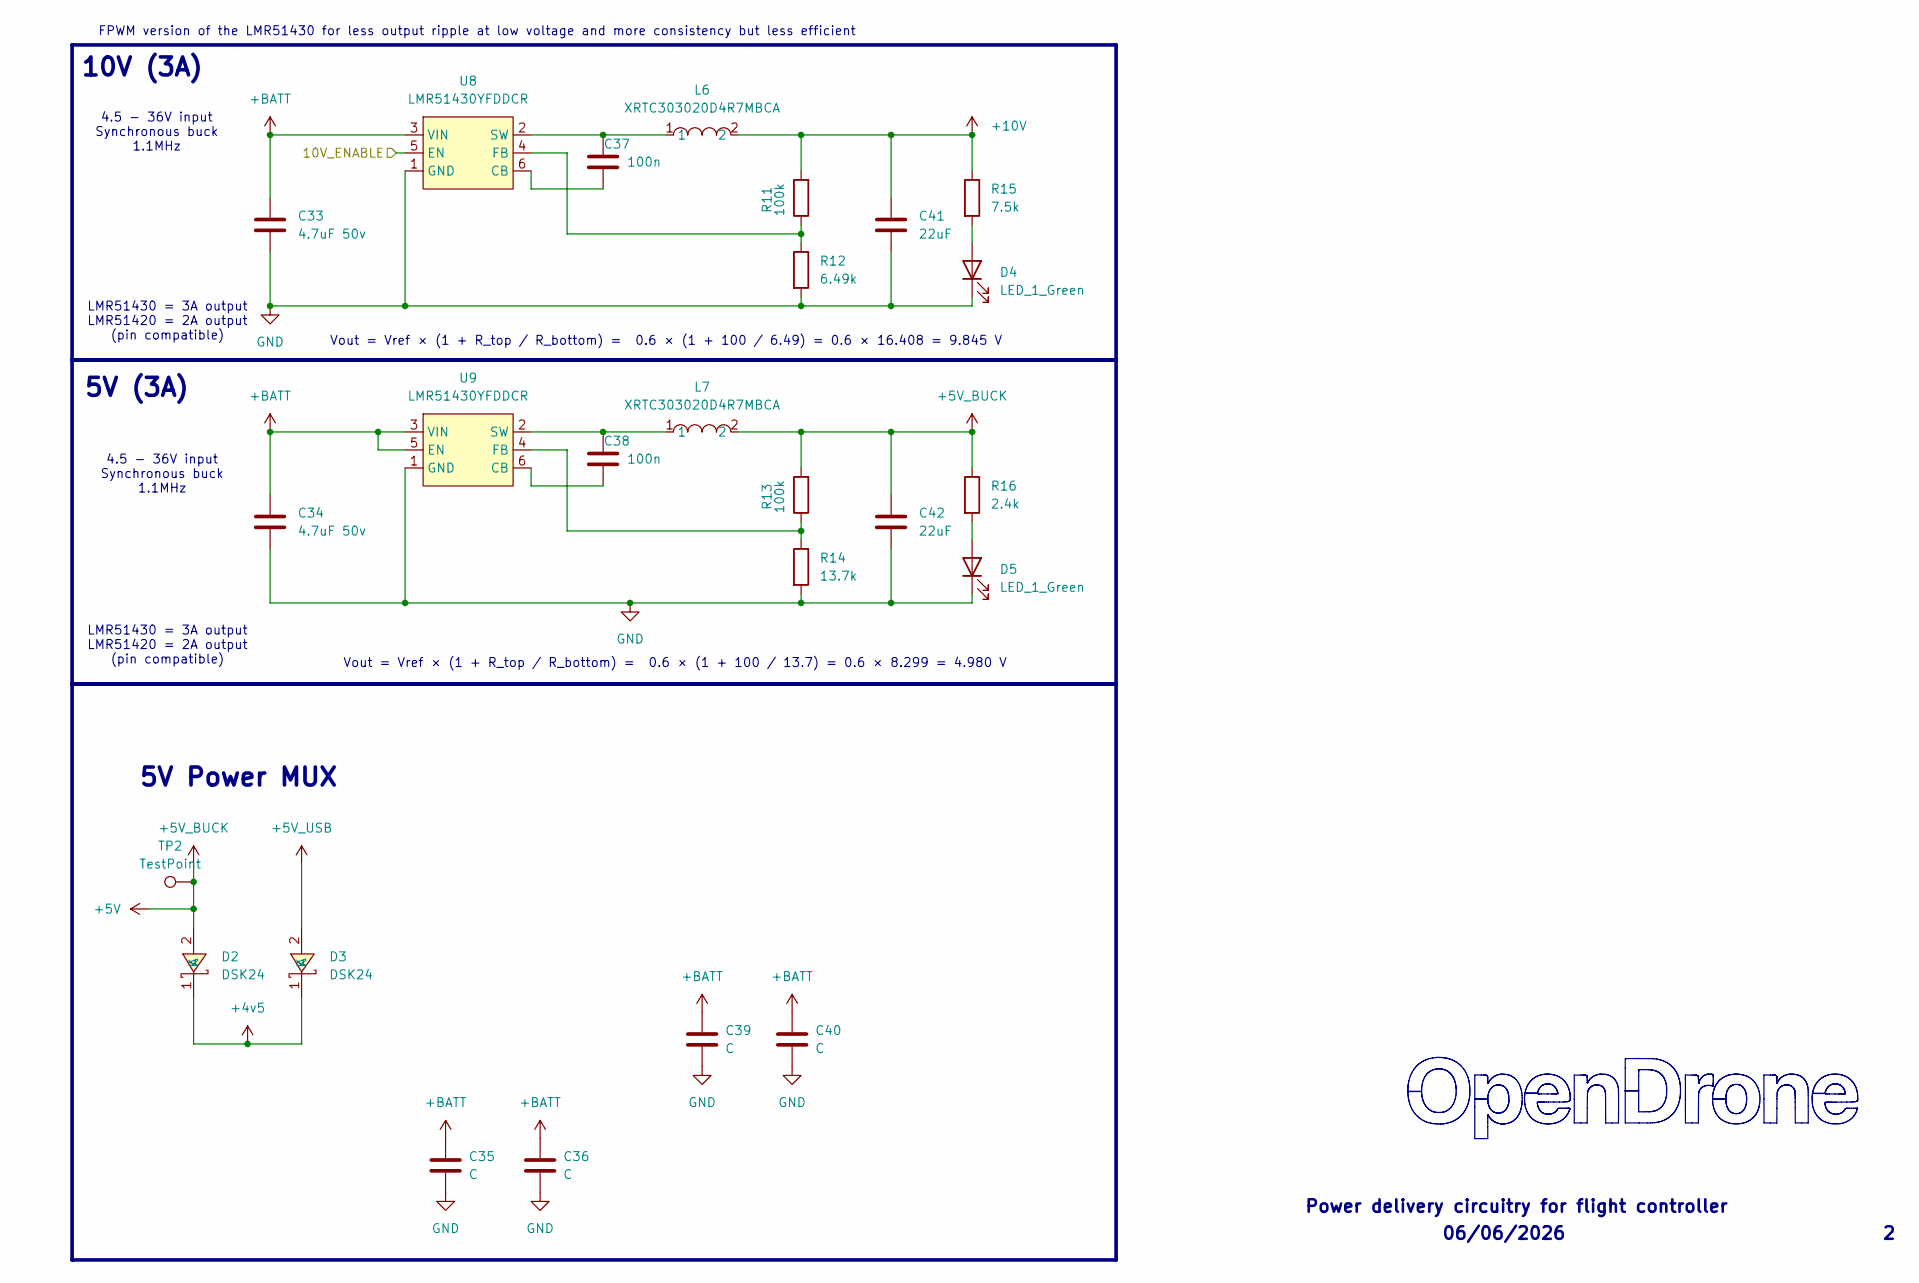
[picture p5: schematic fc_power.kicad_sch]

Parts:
C33, C34: 4.7uF 50v; C_0805_2012Metric; MPN CL21A475KBQNNNE; LCSC C98192
C35, C36: C; C_0805_2012Metric
C37, C38: 100n; C_0201_0603Metric; MPN GRM033R61E104KE14D; LCSC C76939
C39, C40: C; C_1206_3216Metric
C41, C42: 22uF; C_0603_1608Metric; MPN CL10A226MO7JZNC; LCSC C2762594
D2, D3: DSK24; SOD-123_L2.8-W1.8-LS3.7-RD; MPN DSK24; LCSC C64890
D4, D5: LED_1_Green; LED_0402_1005Metric; MPN XL-1005UGC; LCSC C965793
L6, L7: XRTC303020D4R7MBCA; IND-SMD_L3.0-W3.0_AFE303020S; MPN XRTC303020D4R7MBCA; LCSC C39846837
R11, R13: 100k; R_0201_0603Metric; MPN 0201WMF1003TEE; LCSC C270364
R12: 6.49k; R_0201_0603Metric; LCSC C2107920
R14: 13.7k; R_0201_0603Metric; MPN RC-01W1372FT; LCSC C320695
R15: 7.5k; R_0201_0603Metric; LCSC C474437
R16: 2.4k; R_0201_0603Metric; LCSC C166281
TP2: TestPoint; TestPoint_Pad_D1.0mm
U8, U9: LMR51430YFDDCR; SOT-23-6_L2.9-W1.6-P0.95-LS2.9-BL; MPN LMR51430YFDDCR; LCSC C5219261

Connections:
+4v5: D2.1 (K), D3.1 (K); also elsewhere on the board
+5V: C42.1, D2.2 (A), L7.2, R13.2, R16.1, TP2.1; also elsewhere on the board
+5V_USB: D3.2 (A); also elsewhere on the board
+10V: C41.1, L6.2, R11.2, R15.1; also elsewhere on the board
+BATT: C33.1, C34.1, C35.1, C36.1, C39.1, C40.1, U8.3 (VIN), U9.3 (VIN), U9.5 (EN); also elsewhere on the board
/Power/10V_ENABLE: U8.5 (EN); also elsewhere on the board
GND: C33.2, C34.2, C35.2, C36.2, C39.2, C40.2, C41.2, C42.2, D4.1 (K), D5.1 (K), R12.2, R14.2, U8.1 (GND), U9.1 (GND); also elsewhere on the board
unnamed: D4.2 (A), R15.2
unnamed: D5.2 (A), R16.2
unnamed: C37.2, U8.6 (CB)
unnamed: R11.1, R12.1, U8.4 (FB)
unnamed: C37.1, L6.1, U8.2 (SW)
unnamed: C38.2, U9.6 (CB)
unnamed: R13.1, R14.1, U9.4 (FB)
unnamed: C38.1, L7.1, U9.2 (SW)

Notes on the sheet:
Vout = Vref × (1 + R_top / R_bottom) = 0.6 × (1 + 100 / 13.7) = 0.6 × 8.299 = 4.980 V
4.5 - 36V input Synchronous buck 1.1MHz
5V Power MUX
10V (3A)
Vout = Vref × (1 + R_top / R_bottom) = 0.6 × (1 + 100 / 6.49) = 0.6 × 16.408 = 9.845 V
06/06/2026
FPWM version of the LMR51430 for less output ripple at low voltage and more consistency but less efficient
5V (3A)
LMR51430 = 3A output LMR51420 = 2A output (pin compatible)
Power delivery circuitry for flight controller

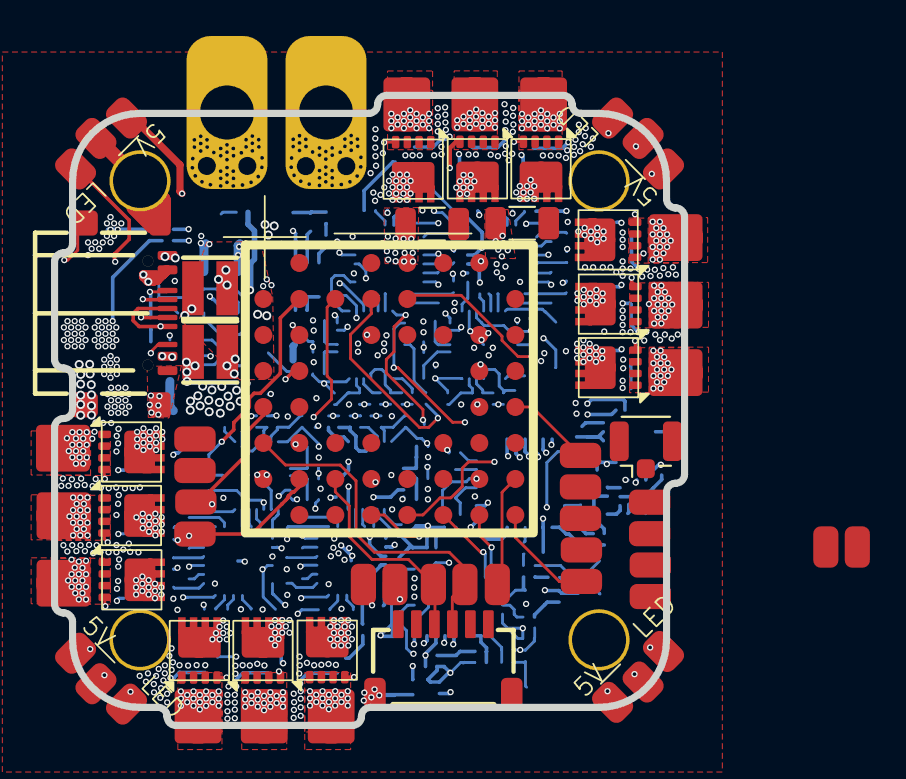
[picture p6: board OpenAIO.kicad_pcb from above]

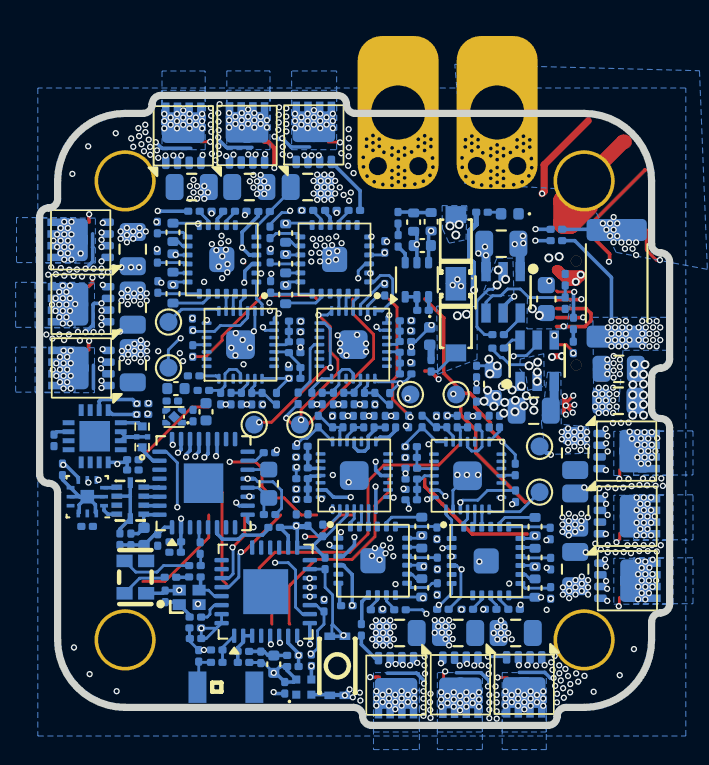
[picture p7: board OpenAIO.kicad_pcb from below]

Board: 8 copper layers, 35.0 x 35.0 mm, 285 parts (232 on the bottom side), 215 nets.

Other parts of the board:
R36, R74, R75: 15R; R_0201_0603Metric
R41: 10R; R_0201_0603Metric
R65, R71, R77: 10k; R_0201_0603Metric

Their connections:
+3V3: R41.2; also elsewhere on the board
/ESC2/GHA: R36.1; also elsewhere on the board
/ESC2/vdda: R41.1; also elsewhere on the board
/ESC3/FBA: R65.1; also elsewhere on the board
/ESC3/FBC: R71.2; also elsewhere on the board
/ESC3/FBCOMMON: R65.2, R71.1; also elsewhere on the board
/ESC4/GHA: R74.1; also elsewhere on the board
/ESC4/GLA: R75.1; also elsewhere on the board
GND: R77.2; also elsewhere on the board
unnamed 141: R36.2; also elsewhere on the board
unnamed 153: R74.2; also elsewhere on the board
unnamed 154: R75.2; also elsewhere on the board
unnamed 202: R77.1; also elsewhere on the board

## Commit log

2026-04-11 Reorganize project tree, consolidate into single local library
    - Re-fetch all 9 schematics verbatim from source repos (OpenFC-ECO,
    4in1ESC 2, OpenRX-Lite) into schematics/{fc,esc,elrs}/
    - Merge symbols/footprints/3D models into libs/lib.{kicad_sym,pretty,3dshapes}
    - Extract only symbols/footprints actually referenced by schematics (43
    symbols, 44 footprints, 38 3D models) — no dead bloat
    - Rewrite schematic lib_ids to single `lib:` nickname via kicad-skip
    - Rename-on-collision: components:LMR51420YDDCR -> lib:LMR51420YDDCR_ESC,
    SOT-23-6_L2.9-W1.6-P0.95-LS2.9-BL OpenFC variant -> ..._lib
    - Add MotorPad (single 2.0x2.5mm pad) and BatteryPad (single 4.0x6.0mm
    pad) footprints + symbols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
    [blackbox.kicad_sch, elrs.kicad_sch, esc_channel.kicad_sch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]
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2026-06-12 Refresh design sources: import rev2 sheets + libs from current sibling repos
    FC sheets <- OpenFC-Lite-Mini rev2 (RP2354A, LMR51430 power tree, COS8051 OSD)
    ESC sheets <- 4in1-mini Rev2 (AT32F421 + NSG2065Q + DOY180N03T, INA186 CSA)
    ELRS sheet <- OpenRX-Lite (ESP32-C3 + SX1281, chip antenna)
    Drop-in swaps at paths the root sheet already references; esc_channel
    instantiated 4x from root resolves. esc_main.kicad_sch (4in1-mini top:
    buck/LDO/CSA/TVS/connector) kept as reference, with ESC.kicad_sch beside
    it so its internal channel instances resolve if ever instantiated.
    Libraries replaced wholesale: lib(.kicad_sym/.pretty/.3dshapes) from
    OpenFC-Lite-Mini, components+4in1ESC from 4in1-mini,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
    [ESC.kicad_sch, blackbox.kicad_sch, elrs.kicad_sch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]
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2026-08-05 Adopt OpenDrone repo standard
    - README rewritten to the family structure: overview, Status (Prototype
    pending, design stage), Specifications, Repository layout, Design entry
    points, Build and export, Manufacturing, Contributing, License
    - Deep design detail relocated to hardware/docs/DESIGN.md (key ICs,
    schematic structure, libraries, firmware targets, supply chain)
    - CONTRIBUTING.md, AGENTS.md, CHANGELOG.md added (design milestones)
    - hardware/datasheets/ removed from tracking and gitignored; files stay
    on disk
    - Legacy names (4in1-mini, OpenFC-ECO, 4in1ESC 2) purged from prose;
    OpenESC-20x20 is the current sibling name
    - Fact fixes: single-outline PCB state stated correctly, lib-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
2026-08-06 Rewrite CONTRIBUTING for humans: file locking, render proof, sign-off
    KiCad files cannot be merged, so the doc now leads with claiming files via
    git lfs lock and issue-first discussion, the convention used by LumenPnP and
    Ultimate Hacking Keyboard. Adds .gitattributes marking design files lockable.
    Drops the internal documentation-style rule that meant nothing to contributors.
2026-08-06 docs: fix contradictions and deduplicate
    Every claim re-verified against the committed design files.
    Contradictions:
    - esc_main.kicad_sch is not instantiated by the root sheet, so its
    buck, LDO and input TVS reach no exported BOM. DESIGN.md now says
    where each ESC part lives; SOURCING flags the two affected rows.
    - SOURCING no longer claims zero Basic parts. The table surveys
    semiconductors and connectors only; four 0402 caps in the
    instantiated sheets (C15525, C23733, C307331, C52923) are Basic.
    - The ELRS sheet carries the generic MCU_Espressif:ESP32-C3 symbol
    with no MPN or LCSC, not the documented ESP32-C3FH4. Documented as
    a pending fix instead of asserted as the design.
    -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
2026-08-11 docs: ask contributors to raise proposals in Discord first
    CONTRIBUTING.md now points at the Discord server and asks contributors to tag
    the developers before opening an issue or starting work, so proposals get
    checked against work in progress, board locks and committed production runs.
2026-08-13 Reset to the planned shape: a specification, not a half-drawn design
    The repo claimed more than it had. The KiCad project was sheets imported wholesale from OpenFC-Lite, OpenESC and OpenRX and stitched together. Its board carried 360 footprints, 784 tracks and 134 zones, byte-identical to OpenAIO-Whoop, which two different products cannot be.
    A planned repo is three files plus research. README.md is now the
    specification: what we want built, why, the requirements, prior art in the
    line, and the open questions that have to be answered before anything gets
    drawn. Answering those needs no KiCad and is where this repo needs help.
    The component and market research is kept, moved to research/, b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
    [ESC.kicad_sch, OpenAIO.kicad_pcb, OpenAIO.kicad_sch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]
2026-08-13 Reset to the planned shape: a specification, not a half-drawn design (#9)
    The component and market research is kept, moved to researc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
    [ESC.kicad_sch, OpenAIO.kicad_pcb, OpenAIO.kicad_sch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]
2026-08-15 README: planned-stage shape from the template
    Badge row, maintainer line, Why, target Specifications, Constraints, Prior
    art with the research files linked, Open questions. Content unchanged in
    substance; the reset design is pointed at via research/DESIGN.md and the
    pre-reset tag.
2026-08-15 Start the KiCad project from the template
    Project files from hardware-template, renamed to OpenAIO. Shared catalogue
    through the OPENDRONE_LIB path variable rather than a submodule: one
    KiCad-Library checkout per machine, project-local lib tables. The proven
    sub-sheets of OpenFC-Lite-Mini, OpenESC-20x20 (one channel) and OpenRX-Lite
    are copied verbatim into hardware/ for Import Sheet; the FC local library is
    copied into lib so they resolve, and the source nicknames are aliased onto
    the catalogue in the lib tables.
    [OpenAIO.kicad_pcb, OpenAIO.kicad_sch, esc_channel.kicad_sch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]
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2026-08-15 Net classes: VBAT, Phase, Power, Gate, USB, RF, Analog with colours and patterns
    Replaces the stale 50Ohm /ELRS/* patterns inherited from the template.
    Widths and clearances start from the line standard (0.09/0.09, via 0.35/0.20)
    and the ESC boards' practice; USB and RF geometry still to be checked against
    the chosen JLCPCB 6-layer stackup.
    [OpenAIO.kicad_sch, esc_channel.kicad_sch, fc_blackbox.kicad_sch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]
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2026-08-15 Design rules: 2 oz outer copper on, 0.16 mm clearance and track width on outer layers
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2026-08-16 OpenAIO: two-board stack tooling, Base + Core over an interior LGA
    One project, one schematic, one master PCB; the shippable boards are derived.
    tools/lga_gen.py: pin table -> Core_LGA_land, Core_LGA_pads (X pre-mirrored
    for B.Cu), symbol Core_LGA, core_interface sheet with global labels.
    tools/lga_wire_root.py: sheet on the root, global labels on the RP2354A wires,
    USB_D+/- in fc_rp2350a, root CURR hier label made global (closes the CSA link).
    tools/lga_place.py: J90 on the Base, J91 flipped on the Core, paths set.
    tools/split_boards.py: export/OpenAIO-Base and -Core, DRC, Core STEP as J90
    3D model plus outline shadow in the master. USB netclass patterns *D+/*D-.
    AGENTS.md: architecture, de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
    [OpenAIO.kicad_pcb, OpenAIO.kicad_sch, core_interface.kicad_sch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]
2026-08-16 OpenAIO: 2 oz outer rules apply to the Base only, Core rule area for 1 oz
    The .kicad_dru 2 oz clearance/track rules skip the rule area named Core;
    tools/lga_core_area.py draws it over the Core island from its Edge.Cuts.
    [OpenAIO.kicad_pcb]
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2026-08-16 OpenAIO: split_boards derives the Core STEP at 0.8 mm (stackup scaled) with project 3D models resolved
    KiCad builds the STEP body from the stackup, not the thickness field, so the
    derived Core file gets its dielectric layers scaled; export/lib.3dshapes is
    symlinked so ${KIPRJMOD} models resolve for the derived board. .wrl-only
    models are reported as skipped.
    [OpenAIO.kicad_pcb]
2026-08-16 split_boards exports the Core as VRML for J90's model so every part shows in the master 3D view
    kicad-cli STEP export skips .wrl-only models; the VRML exporter embeds all of
    them. Units tenths, origin at J91, raised by thickness/2 so the .wrl and the
    .step share offset 0 and --subst-models stays consistent.
2026-08-16 OpenAIO root schematic uuid = project top_level_sheets uuid, so kicad-cli resolves the sheet instances
    KiCad 10 keeps the root sheet uuid in the .kicad_pro; the file still carried an
    older uuid, so kicad-cli sch export netlist/erc fell back to the symbols'
    default references (U11 x4 across the ESC sheets, 'annotation errors' warning,
    55 phantom wire_dangling). GUI was unaffected. Metadata-only, one line.
    [OpenAIO.kicad_sch]
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2026-08-16 OpenAIO: LGA pins from Stan's marker test points, 30 pads, J90/J91 regenerated and placed
    lga_gen.py --from-base reads the marker test points on the Base (position +
    net) into its pin table and generates footprints, symbol and interface
    sheet; lga_apply.py replaces the markers with J90 at the pattern centre and
    J91 on the Core, marks the marker symbols exclude-from-board and adds the
    LED_STRIP global label on the root (it now crosses the LGA). Plugin update
    assigned all 30 pad nets on both boards.
    [OpenAIO-Base.kicad_pcb, OpenAIO-Core.kicad_pcb, OpenAIO.kicad_sch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]
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2026-08-16 OpenAIO: new marker test points TP29 (BUZZER-) and TP30 (+5V) on the Base; lga_apply only excludes the markers it consumed
    [OpenAIO-Base.kicad_pcb, OpenAIO-Core.kicad_pcb, OpenAIO.kicad_sch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]
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2026-08-16 OpenAIO: LGA 31 pins (+5V and BUZZER- added, stray GND removed), J91 follows the pattern centre automatically
    [OpenAIO-Base.kicad_pcb, OpenAIO-Core.kicad_pcb, OpenAIO.kicad_sch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]
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2026-08-17 Base: routing progress (~60%), netclass clearances relaxed
    VBAT/Phase/Power/RF clearance lowered toward the 0.09 line standard; the
    2 oz outer rule in the DRU still enforces 0.16 on F/B.Cu. Schematic sheets
    resaved by eeschema, no circuit change.
    [OpenAIO-Base.kicad_pcb, OpenAIO.kicad_sch, core_interface.kicad_sch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]
2026-08-22 3D models: retarget to KiCad stock, fix placement
    Replaces easyeda2kicad 3D models with KiCad's own where a dimension-matched
    equivalent exists. The easyeda models run 20-100x denser for the same package
    and most carry the LCEDA watermark modelled as raised geometry, which renders
    on every CAD picture of the board and is not on the real part.
    Only the (model ...) reference, offset and rotation are touched. No footprint,
    pad, land pattern, net, placement or value is modified. Applied to the footprint
    LIBRARY and the boards together: fixing only the .pretty is invisible because
    each board carries its own footprint copy, and fixing only the .kicad_pcb is
    surface level because the next placemen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
2026-08-26 Type-C front end back on the root, missing parts placed on the board
    Root sheet: USB1, R3, R4 and their power flags redrawn after the core swap.
    Board: C25, C27, D7, R23 and J35 to J55 placed, Card1, R34 and C36 removed,
    24 of the stubs left at the old J90 pads cleaned up.
    [OpenAIO.kicad_pcb, OpenAIO.kicad_sch, esc_channel.kicad_sch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]
2026-08-26 docs: OpenAIO is the one AIO, 2-6S not 6S
    The esc_channel sheet is the manufactured OpenESC-20x20 stage, which already
    ships specified 2-6S, so the low end costs nothing. NSG2065Q is 5-20 V supply
    with 4.5 V UVLO forward, so at 2S the +10V buck runs in pass-through and the
    drivers see about 5.9 V.
    Adds a Voltage envelope section to AGENTS.md: 30 V DOY180N03T sets the 6S
    ceiling, and the 40 V SP40N01GHNK that takes OpenESC-30x30 to 8S is PDFN-8L
    5x6, which does not fit four channels on 25.5 mm. Also records that gate drive
    at 2S is about half, so the 2S continuous current is not the 6S figure and
    neither goes in the README table before it is measured.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
2026-10-15 One board from the owner's 2026-08-22 Base and Core, BMP580 baro (#26)
    The board is rebuilt from d81e559 (the hand-routed Base recovered from KiCad
    local history and the hand-routed Core of 1fe3d21) plus the always-on +10V of
    9aba717, instead of the agent-reworked 8fa8d7b. Both layouts sit side by side
    in hardware/OpenAIO.kicad_pcb with all routing kept (2513 tracks, 1577 vias),
    on the OpenAIO-Whoop 8L HDI stackup.
    - Schematic: Core_Interface (J90/J91 LGA) removed; U26 BMP580 + C107/C108 on
    I2C0 at 0x47 (Betaflight BMP5xx default). Netlist otherwise identical to
    9aba717; ERC 31 errors, the 9aba717 baseline.
    - Board: Base netclasses and severities; rule area "Core layout" keeps the
    Cor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
2026-10-15 Library: every symbol, footprint and 3D model project-local (#28)
    * Owner: board cleanup, Core placed on the board
    * Library: every symbol, footprint and 3D model project-local
    - 3D models: 275 board model paths and 28 lib.pretty footprints pointed at
    KiCad's stock install or at ${OPENDRONE_LIB} (which this machine's KiCad sets
    to a path that does not exist, so 9 models were missing). All now resolve to
    ${KIPRJMOD}/lib.3dshapes; the three missing ones come from the repo's
    KiCad-Library submodule. .wrl replaced by the .step sibling where one exists.
    - Symbols: the 14 stock symbols (Device, power, Connector, Connector_Generic,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
2026-10-15 8 layers on the OpenAIO-Whoop plan; /CSA+ corridor; power path tool (#31)
    - 12L -> 8L HDI 1+6+1, 1.0 mm, 1 oz on all layers (OpenAIO-Whoop stackup,
    NextPCB-confirmed). Layers: L2/L7 GND, L3 Base signals, L4 +BATT, L5 rails,
    L6 Core signals + 5V; today's tracks packed by origin (6 segments collide).
    - Vias retyped (buried 0.33/0.15), nudged, widths standardised.
    - /CSA+ corridor on all layers between the battery + pad and the shunt:
    0.726 -> 0.431 mOhm.
    - tools/power_paths.py: resistance and loss of every high-current path.
    At 61 A: 8L before 5.4 W, 12L 6.6 W, 8L now 3.6 W.
    - Layer names, Cmts.User plan and via layer pairs for 8 layers; docs and the
    reroute plan in research/ROUTING.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
2026-10-15 One 3.3 V rail: U7 becomes TLV76733DRVR (1 A), U23 removed
    - U7 LP5912-3.3DRVR (500 mA) -> TLV76733DRVR (1 A, LCSC C2848334, as on
    OpenESC-20x20), same WSON-6 2x2 land; SNS (pin 2) tied to OUT in the
    schematic and by a 0.25 mm jumper on B.Cu.
    - U23 TLV75533 removed; the 17 +3V3 power symbols are +3.3V, and the board's
    +3V3 copper (24 tracks, 6 vias, 3 pours) moved onto +3.3V.
    - Netlist: only U7 (value, MPN, LCSC, pin 2), U23 gone, +3V3 merged into +3.3V.
    ERC 31 errors as before. DRC: no new unconnected beyond the link the old
    +3V3 side now needs to U7.
    - Docs: ROUTING.md rails and reroute step; firmware notes on the single rail
    (ISSUES I15 resolved).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
2026-10-15 Every via at the stackup minimum
    tools/via_min.py: microvia 0.25/0.10, buried and through 0.33/0.15. 641 vias
    shrunk; 156 stub tracks keep connections that only the larger land made; 14
    through vias keep 0.35-0.5 because only their larger land reaches a pour.
    DRC 449 -> 435 errors, unconnected unchanged (67, same nets); power paths
    unchanged (3.64 W at 61 A).
2026-10-15 Pours at 0.10 mm clearance (1 oz minimum, was the 2 oz 0.16), vias nudged
    DRC 240 -> 147 errors, copper shorts 89 -> 60, GND return 0.234 -> 0.100 mOhm.
2026-10-15 DRC errors to zero: conflicting vias and tracks deleted
    tools/drc_zero.py deleted the item of each error pair that costs least: 66 vias
    (33 of them GND stitching) and 44 track segments (44 mm). Footprint-intrinsic
    cases are DRU rules (U9 X2SON land, USB1 peg to R4) or exclusions (USB1 peg
    annular ring). DRC 147 -> 0 errors, copper shorts 60 -> 0; unconnected
    118 -> 157 (owner: to reroute).
2026-10-15 Project setup: vias at minimum by default, phase and gate net classes apply
    - Every net class: via 0.33/0.15, microvia 0.25/0.10, so V / Shift+V place
    minimum vias (VBAT and Phase were 0.5/0.3, Power 0.45/0.25, others 0.35/0.2).
    - Net class patterns: phase nets /1A../4C -> Phase, Net-(Q*-G) -> Gate (the
    Base patterns matched no net). Clearance: Power and VBAT 0.10, Phase and
    Gate 0.09 (as routed; 25 V inner, IPC-2221 B1 0.05).
    - Track width presets 0.10 / 0.25 / 0.30 / 0.50 / 1.0.
    - DRC: 2 errors left, the owner's overlapping +BATT vias at (73.6, 72.7).
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2026-10-15 Edit form for routing: one via per connection; via keys back to KiCad defaults
    - 804 microvia + buried stacks collapsed to one 0.33/0.15 via each (through,
    or blind L1-L7 / L2-L8), nudged; drc_zero removed 18 redundant vias (14 GND).
    DRC 0 errors, pad connectivity unchanged, 139 unconnected.
    - via_types.py also converts edit-form blind vias; dry run on this board
    rebuilds 642 stacks and 170 microvias.
    - Cheat sheet on Cmts.User and ROUTING.md: the routing workflow and the final
    conversion pass.
2026-10-15 Edit form: no microvias on non-GND nets
    23 single microvias on non-GND nets ended in the L2/L7 GND planes with no copper
    of their net there; each is now the normal edit-form via (0.33/0.15, L1-L7 or
    L2-L8). Nudged; drc_zero removed 9 vias and 1 track that had no room. DRC 0
    errors, pad connectivity unchanged, 142 unconnected. Microvias remain only on
    GND (into the planes); via_types.py rebuilds stacks at the end.
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2026-10-15 Power copper: +BATT planes L4/L5, /CSA+ branch, FET pad via arrays
    tools/power_opt.py (pcbnew API, clearance-checked, each stage kept only if
    no net gets more unconnected):
    | Path (61 A, v2 solver) | Before | After |
    |---|---|---|
    | /CSA+ batt pad to shunt | 0.385 mOhm, 1.43 W | 0.151 mOhm, 0.56 W |
    | +BATT | open, 20 islands | 0.445 mOhm, 1.66 W |
    | GND | 0.208 mOhm, 0.77 W | 0.221 mOhm, 0.82 W |
    | 12 phases | 0.283 mOhm, 0.25 W | 0.235 mOhm, 0.21 W |
    - +BATT pour L4 + L5 interior, L3/L6 pocket at shunt exit, priority 1
    - /CSA+ second branch L2-L7 below U24.11 mounting hole
    - L1-L2 microvias in high-side source pads, L7-L8 in low-side sources,
    288 GND stitch microvias near low-side FETs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
2026-10-15 Freerouting pass: 117 -> 59 unconnected, escape vias, routing tools
    - tools/fr_prep.py: DSN export, existing copper protected, power nets NOROUTE
    - tools/fr_run.sh: Freerouting 2.5.0 headless, through vias only
    - tools/fr_import.py: adds only the new wires/vias (KiCad's SES import would
    replace all tracks)
    - tools/fr_prune.py: drops autorouted items in DRC errors
    - tools/esc_vias.py: dogbone via for each unrouted SMD pad end without one;
    --blind falls back to L1-L7 / L2-L8 where a through land hits far-side parts
    | | Before | After |
    | Unconnected | 117 | 59 |
    | Tracks / vias added | | 493 / 36 routed, 22 escape |
    | DRC errors | 2 (USB1 pegs) | 2 (USB1 pegs) |
    Co-Authored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
2026-10-15 Routable state: via types by connection, stubs removed, 0 DRC errors
    - 75 +BATT vias stored as microvia L2-L8 (0.15 drill, invalid on 1+6+1)
    re-typed, then tools/via_types.py --buried-size 0.33/0.15 on all
    through/blind/buried vias: through only where F and B copper meet
    - tools/hdi_via_pass.py plan(): a top via that reaches L7 (or a bottom one
    that reaches L2) also needs the buried via (OSD_W L7 jumper was lost)
    - tools/cleanup.py: 18 dead-end vias, 20 dangling track segments
    | | Owner board | Now |
    | DRC errors | 164 | 0 |
    | Unconnected | 63 | 63 (same per net) |
    | Non-GND through vias | 686 | 424 |
    | Non-GND blind (not allowed) | 187 | 0 |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
2026-10-15 Clean-up: dead track chains, AIO logo to B.Silkscreen, co-located holes ignored
    | DRC warning | Before | After |
    | track_dangling | 7 | 0 (34 dead segments + 1 via, chains) |
    | solder_mask_bridge | 109 | 11 (fine-pitch U9/U11, C44/R83, USB1 peg/R4) |
    | holes_co_located | 199 | ignored: microvia-on-buried stacks by design |
    | Errors / unconnected | 0 / 63 | 0 / 63 |
    The "AIO" text was on B.Mask over U26, C82 and vias, exposing copper of
    several nets; it is now silkscreen next to "Open".
    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
2026-10-16 Edit form again: one via per connection, no stacks
    tools/via_collapse.py: each non-GND microvia + buried stack becomes one
    0.33/0.15 via over the layers it spanned (blind L1-L7 / L2-L8, buried L2-L7,
    through where L1 and L8 meet). Vias that would short or crowd a neighbour
    once longer are turned back (--keep). GND keeps its plane microvias.
    | Non-GND stacks | 533 | 1 (+3.3V, would clip /4A on L3) |
    | DRC errors | 2 (/3A via forms) | 0 |
    | Unconnected | 78 | 78 (no net worse) |
    Also: 2 blind L3-L8 vias (/3A, /4A) to L2-L8; a /3A L7-L8 microvia that sat
    inside a blind L3-L8 removed. via_types.py rebuilds the stacks at the end.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
2026-10-16 IO remap: shortest RP2354A runs on the placed board; SBUS back on UART0
    tools/io_opt.py (constraint-checked assignment, research/IO-CONSTRAINTS.md)
    picked the mapping; tools/io_remap_sch.py edits the sheets (sexpdata),
    re-saved with kicad-cli; netlist diff shows only the intended pins changed.
    | Net | GPIO before | GPIO after |
    | MOTOR2 | 24 | 21 |
    | MOTOR3 | 23 | 18 |
    | MOTOR4 | 22 | 8 |
    | SPI0.SCK (SD) | 18 | 22 |
    | FLASH_CS (SD CS) | 21 | 24 |
    | LED_STRIP_L | 8 | 26 |
    | LED0 | 26 | 27 |
    | free | 27 | 23 |
    U2-to-part distance 147.2 -> 136.5 mm; UART, I2C, SPI1, OSD, ADC unchanged.
    SH-6 pin 6 (air unit SBUS) moved from UART1_RX, where it fought the ESP32
    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
2026-10-16 Revert the IO remap and SH-6 pin 6 change: the owner's routing stays
    The pins were routed meanwhile; with that routing counted as rework the
    optimiser keeps today's mapping. SBUS on the ELRS RX line is the owner's
    choice (ELRS unused when the DJI receiver is). Kept: tools/io_opt.py,
    tools/io_remap_sch.py and research/IO-CONSTRAINTS.md for later use.
2026-10-16 ELRS_EN on GPIO27, SWD test pads TP42/TP43
    - GPIO27 (U2.41) -> ESP32-C3 CHIP_EN (net ELRS_EN; R114 keeps ELRS on).
    Betaflight PINIO1 (inverted push-pull) holds ELRS in reset on demand, so
    the DJI SBUS on SH-6 pin 6 can own UART1_RX.
    - SWCLK (U2.24) -> TP42, SWDIO (U2.25) -> TP43, D1.0 pads, parked right of
    the outline for placement.
    - tools/sch_debug_pins.py (sexpdata); netlist diff: only these nets change.
    - Board synced: 0 DRC errors, unconnected 70 -> 72 (ELRS_EN, SWDIO).
    U2 pad 24 (SWCLK) is still missing: pad 23 (+1.1V) cannot escape past XOUT/C4
    and the +3.3V via under it; needs a hand rework of the crystal corner.
2026-10-16 ELRS OFF solder jumper JP2 and 1k R115 on CHIP_EN
    - JP2 (CHIP_EN to GND, new 1.10 x 0.55 mm footprint
    lib:SolderJumper-2_P0.65mm_Tiny_Open, open mask, no paste): bridging it
    holds the ESP32-C3 in reset with any firmware, so an external receiver on
    J54/J55 or the DJI SBUS on SH-6 pin 6 owns UART1.
    - R115 1k between GPIO27 (ELRS_EN) and CHIP_EN: GPIO27 cannot short into a
    bridged jumper (3.3 mA).
    - tools/elrs_jumper.py (pcbnew footprint, sexpdata schematic); netlist diff:
    only CHIP_EN/ELRS_EN/GND gain the new pins. ERC 520 -> 519.
    - Board synced; JP2, R115, TP42, TP43 parked right of the outline for
    placement (they overlap there: 4 shorting errors until placed).
    - R115 has no LCSC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
2026-10-16 Warnings pass: final via stacks, dead stubs, mask-bridge attributes
    - tools/via_types.py final pass (--buried-size 0.33/0.15): 199 edit-form
    blind vias back to microvia + buried stacks. Fixed: the pad-overlap test
    counted outer layers the via does not span (kept 30 blind phase vias and
    put a +3.3V microvia into U9 pad 4). New --skip: 4 short blind pairs
    (UART1_TX, UART1_RX, MOTOR3, LED_STRIP_L) stay as drawn, their L2-L7
    buried via would hit other nets: reroute.
    - Removed dead copper: +5V L3 stub and redundant link (91.1, 48.5),
    DCC_FB L6 chain ending without a via (duplicate of the L8 route).
    - JP2, U9, U11: allow_soldermask_bridges (board and lib); lib U9 takes the
    board's tr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
